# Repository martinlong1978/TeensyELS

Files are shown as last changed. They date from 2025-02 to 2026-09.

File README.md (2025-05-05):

# Teensy Electronic leadscrew
This is an implementation of an electronic leadscrew using a Teensy microcrontroller.

# Architecture
We use [https://platformio.org/](platformio) as the infrastructure to build this project.

# Installation
You will currently need to setup platformio to build this, it can also handle installation to your teensy as well.
NOTE: you will have to modify some of the configuration to get this set up for your particular lathe, instructions coming soon.

# Testing
We aim to have the business logic of this testable locally without having to program any hardware or run tests on hardware (for the most part)
To test you just need to run the `pio test --environment native` command to run what tests we have written

## Debugging
To test this application, you will be limited to setting breakpoints on unit tests only as the Teensy series of boards do not support hardware debuggers directly.

The "blessed" way to debug is to:
- Use vscode
- Set your environment to "native" (this is the default)
- Ensure that 'gdb' is installed
- Set your breakpoints in your code to test
    - note: if you want to debug a single test, set the test name in `test_debug` in platformio.ini
- go to the debug panel in vscode and run the "PIO debug" target
- ???
- Profit!

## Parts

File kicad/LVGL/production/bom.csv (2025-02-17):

Designator | Footprint | Quantity | Value | LCSC Part #
_4, _3, _2, |  | 4
E1 | Sparkfun | 1 | ~
J1 | RJ45_RCH_RC01937 | 1 | RJ45_Shielded
J2 | JST_XH_B4B-XH-A_1x04_P2.50mm_Vertical | 1 | Conn_01x04_Pin
J3 | PinHeader_1x04_P2.54mm_Vertical | 1 | Conn_01x04_Pin
J4 | TerminalBlock_CUI_TB007-508-02_1x02_P5.08mm_Horizontal | 1 | Screw_Terminal_01x02
MCU1 | TTGO-T-Display | 1 | TTGO-T-Display
Q1, Q2, Q3, Q4, Q5, Q6, Q7, Q8 | SOT-23 | 8 | BSS138
R1, R11, R12, R18, R2, R3, R4, R5, R6, R7, R8 | 0805 | 11 | 10K
R10, R9 | 0805 | 2 | 330R
R13, R14 | 0805 | 2 | 0K
R15, R16, R17 | 0805 | 3 | 1K
SW1, SW10, SW2, SW3, SW4, SW5, SW6, SW7, SW8, SW9 | SW_TH_Tactile_Omron_B3F-10xx | 10 | SW_Omron_B3FS
U1 | Teensy41 | 1 | Teensy4.1

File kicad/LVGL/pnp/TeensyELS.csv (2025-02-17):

Id | Designator | Footprint | Quantity | Designation | Supplier and ref
1 | Q3,Q8,Q7,Q2,Q5,Q1,Q4,Q6 | SOT-23 | 8 | BSS138
2 | R18,R4,R11,R12,R7,R1,R6,R3,R15,R17,R16,R5,R2,R8 | R_0805_2012Metric | 14 | 10K
3 | MCU1 | TTGO-T-Display | 1 | TTGO-T-Display
4 | ,,, |  | 4
5 | J2 | JST_XH_B4B-XH-A_1x04_P2.50mm_Vertical | 1 | Conn_01x04_Pin
6 | J4 | TerminalBlock_CUI_TB007-508-02_1x02_P5.08mm_Horizontal | 1 | Screw_Terminal_01x02
7 | U1 | Teensy41 | 1 | Teensy4.1
8 | SW8,SW6,SW1,SW3,SW4,SW2,SW7,SW5,SW9,SW10 | SW_TH_Tactile_Omron_B3F-10xx | 10 | SW_Omron_B3FS
9 | R14,R13 | R_0805_2012Metric | 2 | 0K
10 | R9,R10 | R_0805_2012Metric | 2 | 330R
11 | J1 | RJ45_RCH_RC01937 | 1 | RJ45_Shielded
12 | J3 | PinHeader_1x04_P2.54mm_Vertical | 1 | Conn_01x04_Pin
13 | E1 | Sparkfun | 1 | ~

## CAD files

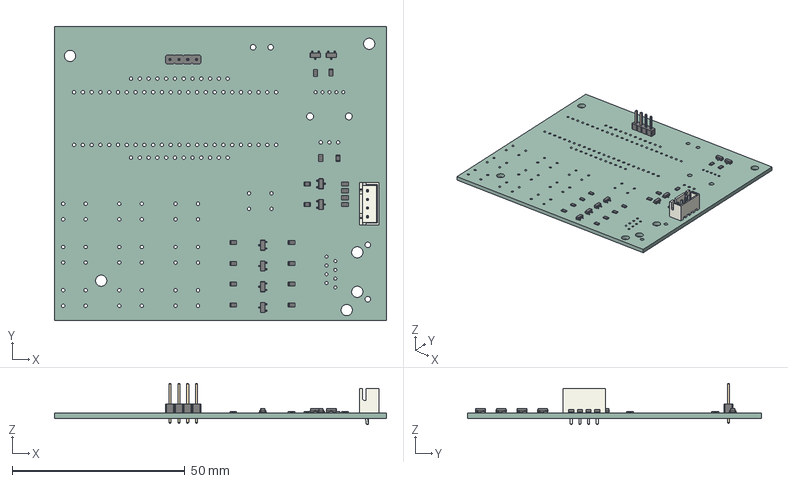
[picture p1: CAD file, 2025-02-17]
kicad/LVGL/TeensyELS.step
96.0 x 85.0 x 11.9 mm
SOT_23 x 8
R_0805_2012Metric x 18
JST_B4B_XH_A
PinHeader_1x04_P254mm_Vertical
TeensyELS_PCB

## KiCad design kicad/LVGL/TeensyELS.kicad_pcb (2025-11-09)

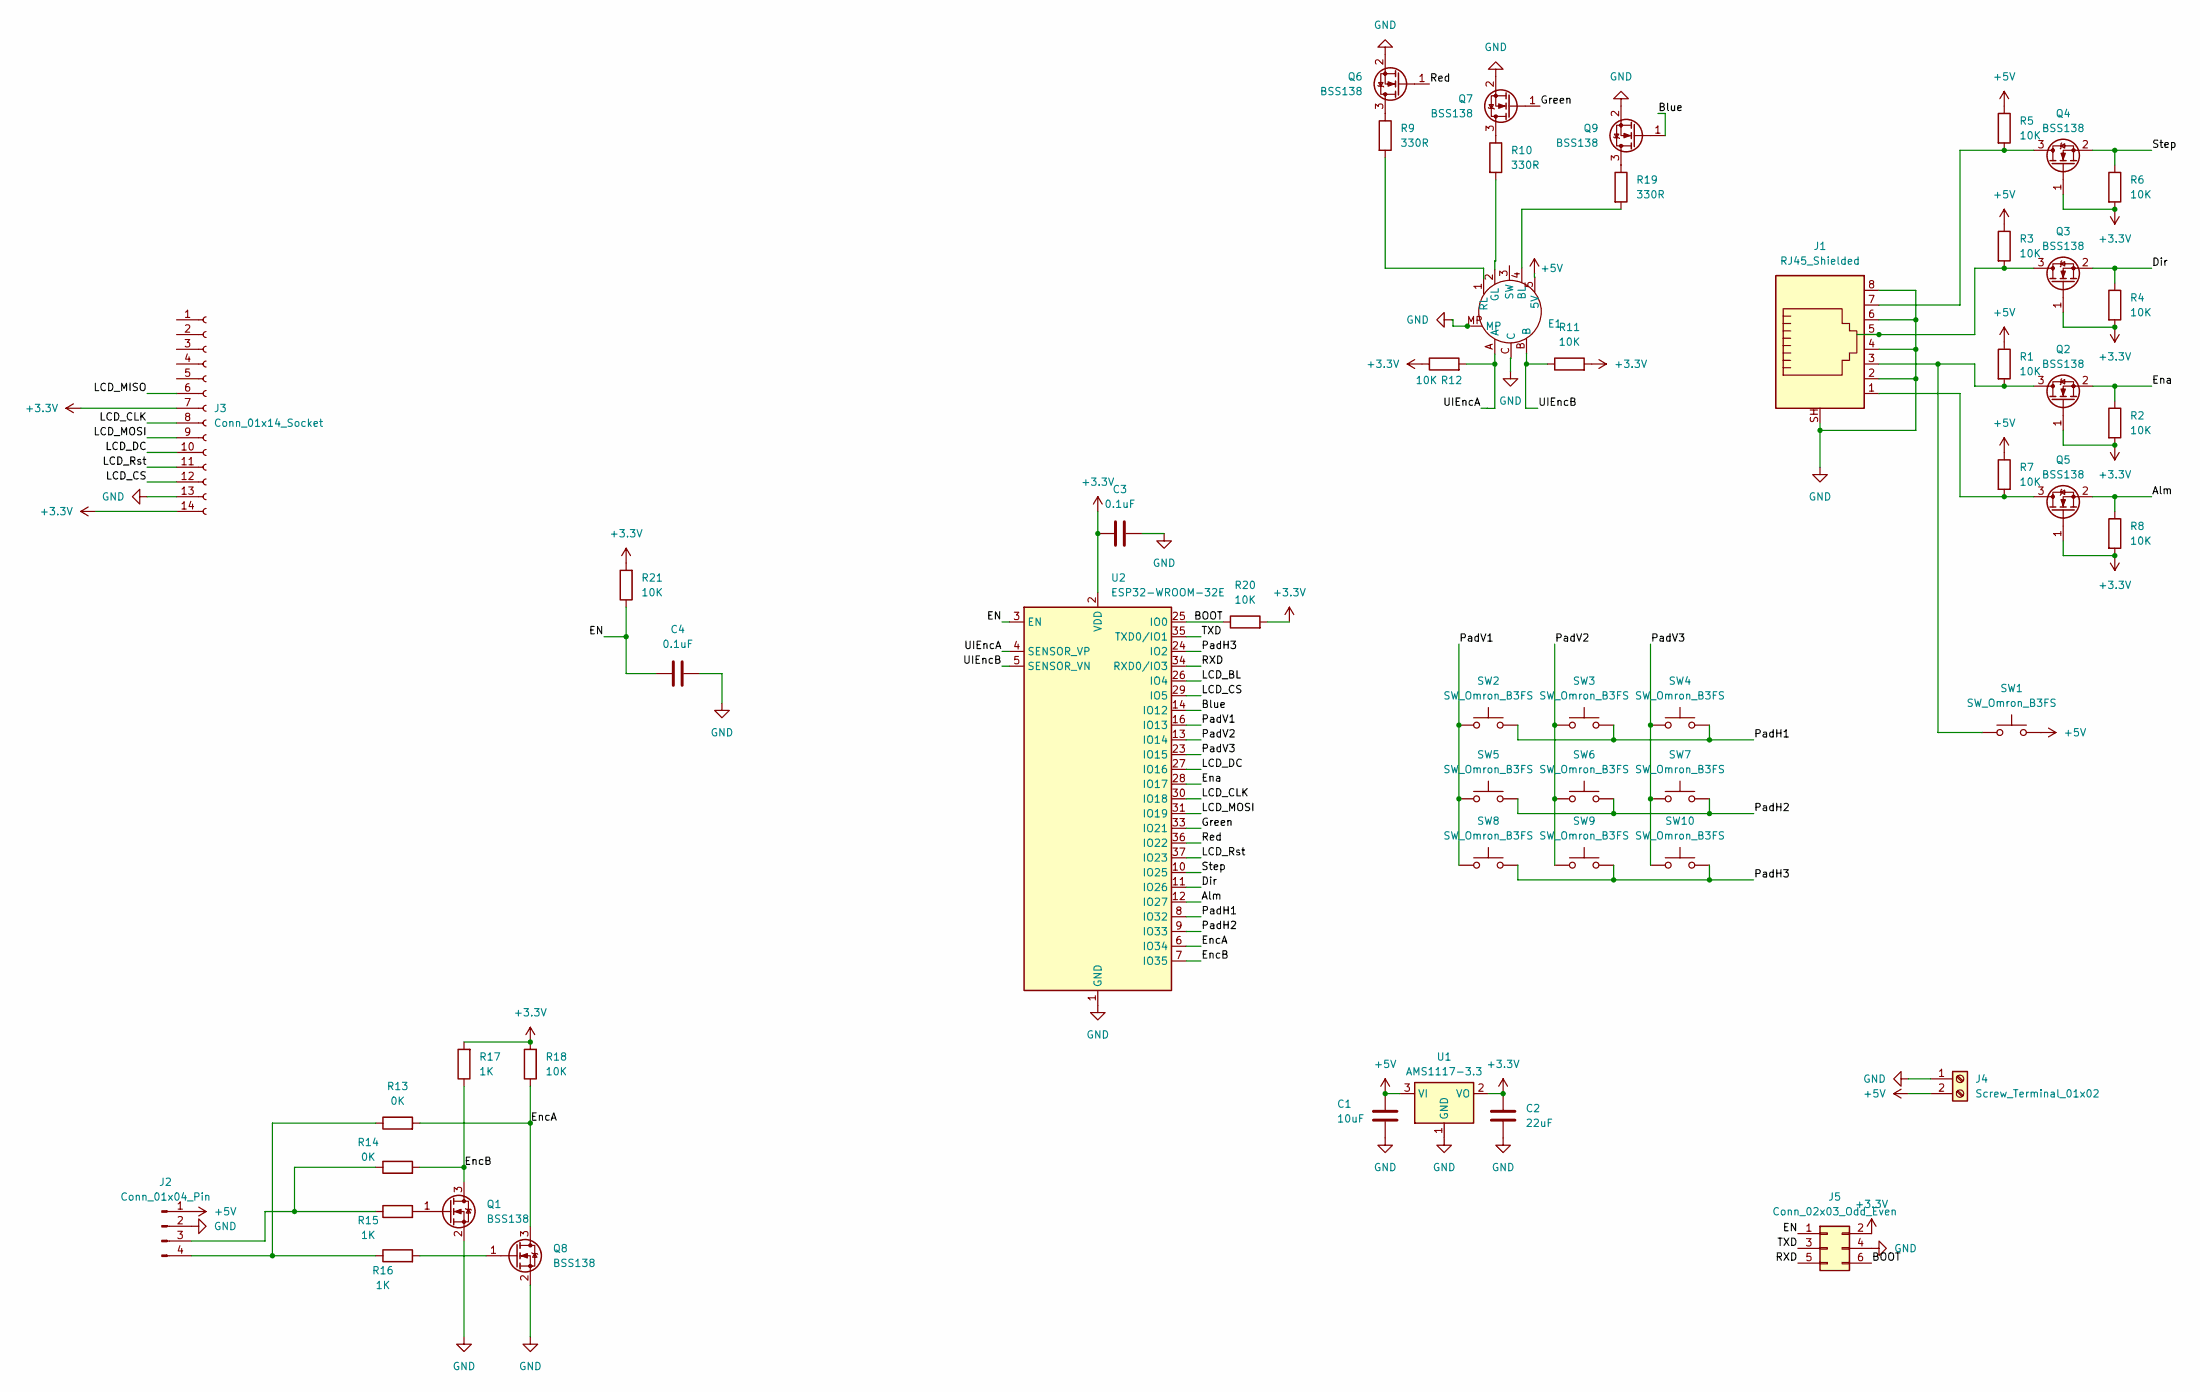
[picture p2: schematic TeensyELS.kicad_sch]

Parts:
C1: 10uF; C_0805_2012Metric
C2: 22uF; C_0805_2012Metric
C3, C4: 0.1uF; C_0805_2012Metric
E1: Sparkfun
J1: RJ45_Shielded; RJ45_RCH_RC01937
J2: Conn_01x04_Pin; JST_XH_B4B-XH-A_1x04_P2.50mm_Vertical
J3: Conn_01x14_Socket; PinHeader_1x14_P2.54mm_Vertical
J4: Screw_Terminal_01x02; TerminalBlock_CUI_TB007-508-02_1x02_P5.08mm_Horizontal
J5: Conn_02x03_Odd_Even; PinHeader_2x03_P1.27mm_Vertical_SMD
Q1, Q2, Q3, Q4, Q5, Q6, Q7, Q8, Q9: BSS138; SOT-23
R1, R2, R3, R4, R5, R6, R7, R8, R11, R12, R18, R20, R21: 10K; R_0805_2012Metric
R9, R10, R19: 330R; R_0805_2012Metric
R13, R14: 0K; R_0805_2012Metric
R15, R16, R17: 1K; R_0805_2012Metric
SW1, SW2, SW3, SW4, SW5, SW6, SW7, SW8, SW9, SW10: SW_Omron_B3FS; SW_TH_Tactile_Omron_B3F-10xx
U1: AMS1117-3.3; SOT-223-3_TabPin2
U2: ESP32-WROOM-32E; ESP32-WROOM-32D

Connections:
+3.3V: C2.2, C3.1, J3.7, J3.14, J5.2, Q2.1 (G), Q3.1 (G), Q4.1 (G), Q5.1 (G), R2.2, R4.2, R6.2, R8.2, R11.2, R12.1, R17.2, R18.2, R20.2, R21.2, U1.2 (VO), U2.2 (VDD)
+5V: C1.2, E1.5 (5V), J2.1, J4.2, R1.1, R3.1, R5.1, R7.1, SW1.2, U1.3 (VI)
/Alm: Q5.2 (S), R8.1, U2.12 (IO27)
/BOOT: J5.6, R20.1, U2.25 (IO0)
/Blue: Q9.1 (G), U2.14 (IO12)
/Dir: Q3.2 (S), R4.1, U2.11 (IO26)
/EN: C4.1, J5.1, R21.1, U2.3 (EN)
/Ena: Q2.2 (S), R2.1, U2.28 (IO17)
/EncA: Q8.3 (D), R13.2, R18.1, U2.6 (IO34)
/EncB: Q1.3 (D), R14.2, R17.1, U2.7 (IO35)
/Green: Q7.1 (G), U2.33 (IO21)
/LCD_BL: U2.26 (IO4)
/LCD_CLK: J3.8, U2.30 (IO18)
/LCD_CS: J3.12, U2.29 (IO5)
/LCD_DC: J3.10, U2.27 (IO16)
/LCD_MISO: J3.6
/LCD_MOSI: J3.9, U2.31 (IO19)
/LCD_Rst: J3.11, U2.37 (IO23)
/PadH1: SW2.2, SW3.2, SW4.2, U2.8 (IO32)
/PadH2: SW5.2, SW6.2, SW7.2, U2.9 (IO33)
/PadH3: SW8.2, SW9.2, SW10.2, U2.24 (IO2)
/PadV1: SW2.1, SW5.1, SW8.1, U2.16 (IO13)
/PadV2: SW3.1, SW6.1, SW9.1, U2.13 (IO14)
/PadV3: SW4.1, SW7.1, SW10.1, U2.23 (IO15)
/RXD: J5.5, U2.34 (RXD0/IO3)
/Red: Q6.1 (G), U2.36 (IO22)
/Step: Q4.2 (S), R6.1, U2.10 (IO25)
/TXD: J5.3, U2.35 (TXD0/IO1)
/UIEncA: E1.A, R12.2, U2.4 (SENSOR_VP)
/UIEncB: E1.B, R11.1, U2.5 (SENSOR_VN)
GND: C1.1, C2.1, C3.2, C4.2, E1.C, E1.MP, J1.2, J1.4, J1.6, J1.8, J1.SH, J2.2, J3.13, J4.1, J5.4, Q1.2 (S), Q6.2 (S), Q7.2 (S), Q8.2 (S), Q9.2 (S), U1.1 (GND), U2.1 (GND), U2.15 (GND), U2.38 (GND), U2.39 (GND)
unnamed: E1.4 (BL), R19.2
unnamed: E1.2 (GL), R10.2
unnamed: E1.1 (RL), R9.2
unnamed: J2.3, R14.1, R15.1
unnamed: J2.4, R13.1, R16.1
unnamed: Q1.1 (G), R15.2
unnamed: J1.3, Q2.3 (D), R1.2, SW1.1
unnamed: J1.5, Q3.3 (D), R3.2
unnamed: J1.7, Q4.3 (D), R5.2
unnamed: J1.1, Q5.3 (D), R7.2
unnamed: Q6.3 (D), R9.1
unnamed: Q7.3 (D), R10.1
unnamed: Q8.1 (G), R16.2
unnamed: Q9.3 (D), R19.1

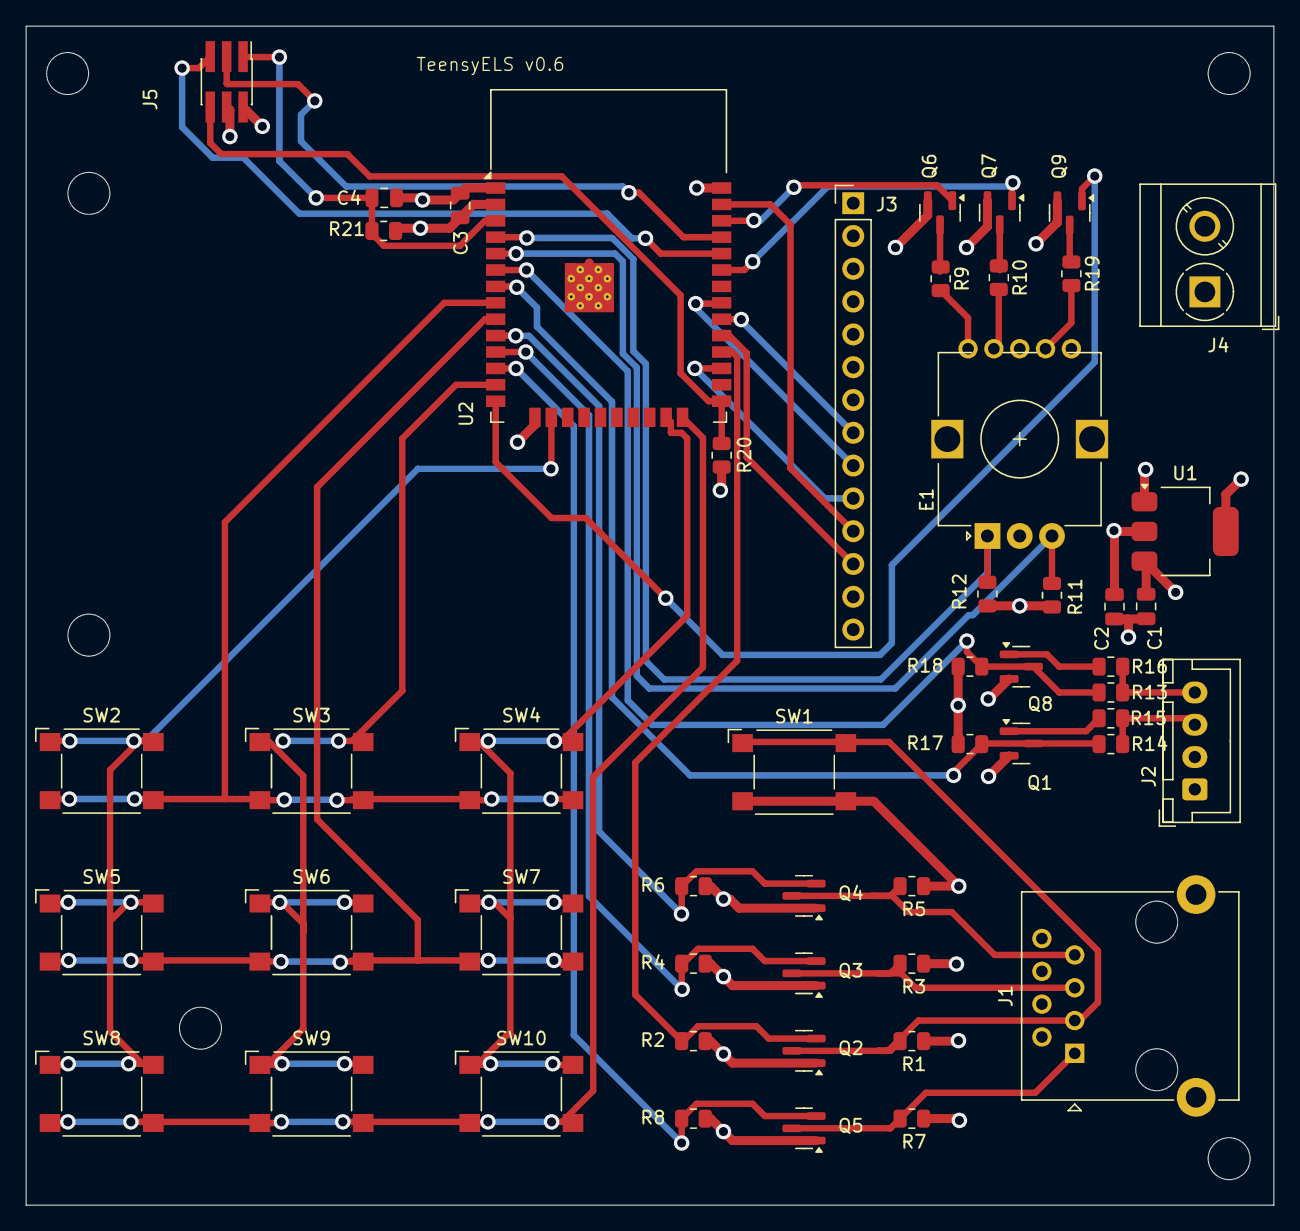
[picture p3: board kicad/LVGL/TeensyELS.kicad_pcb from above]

Board: 4 copper layers, 96.6 x 91.3 mm, 52 parts (0 on the bottom side), 43 nets.

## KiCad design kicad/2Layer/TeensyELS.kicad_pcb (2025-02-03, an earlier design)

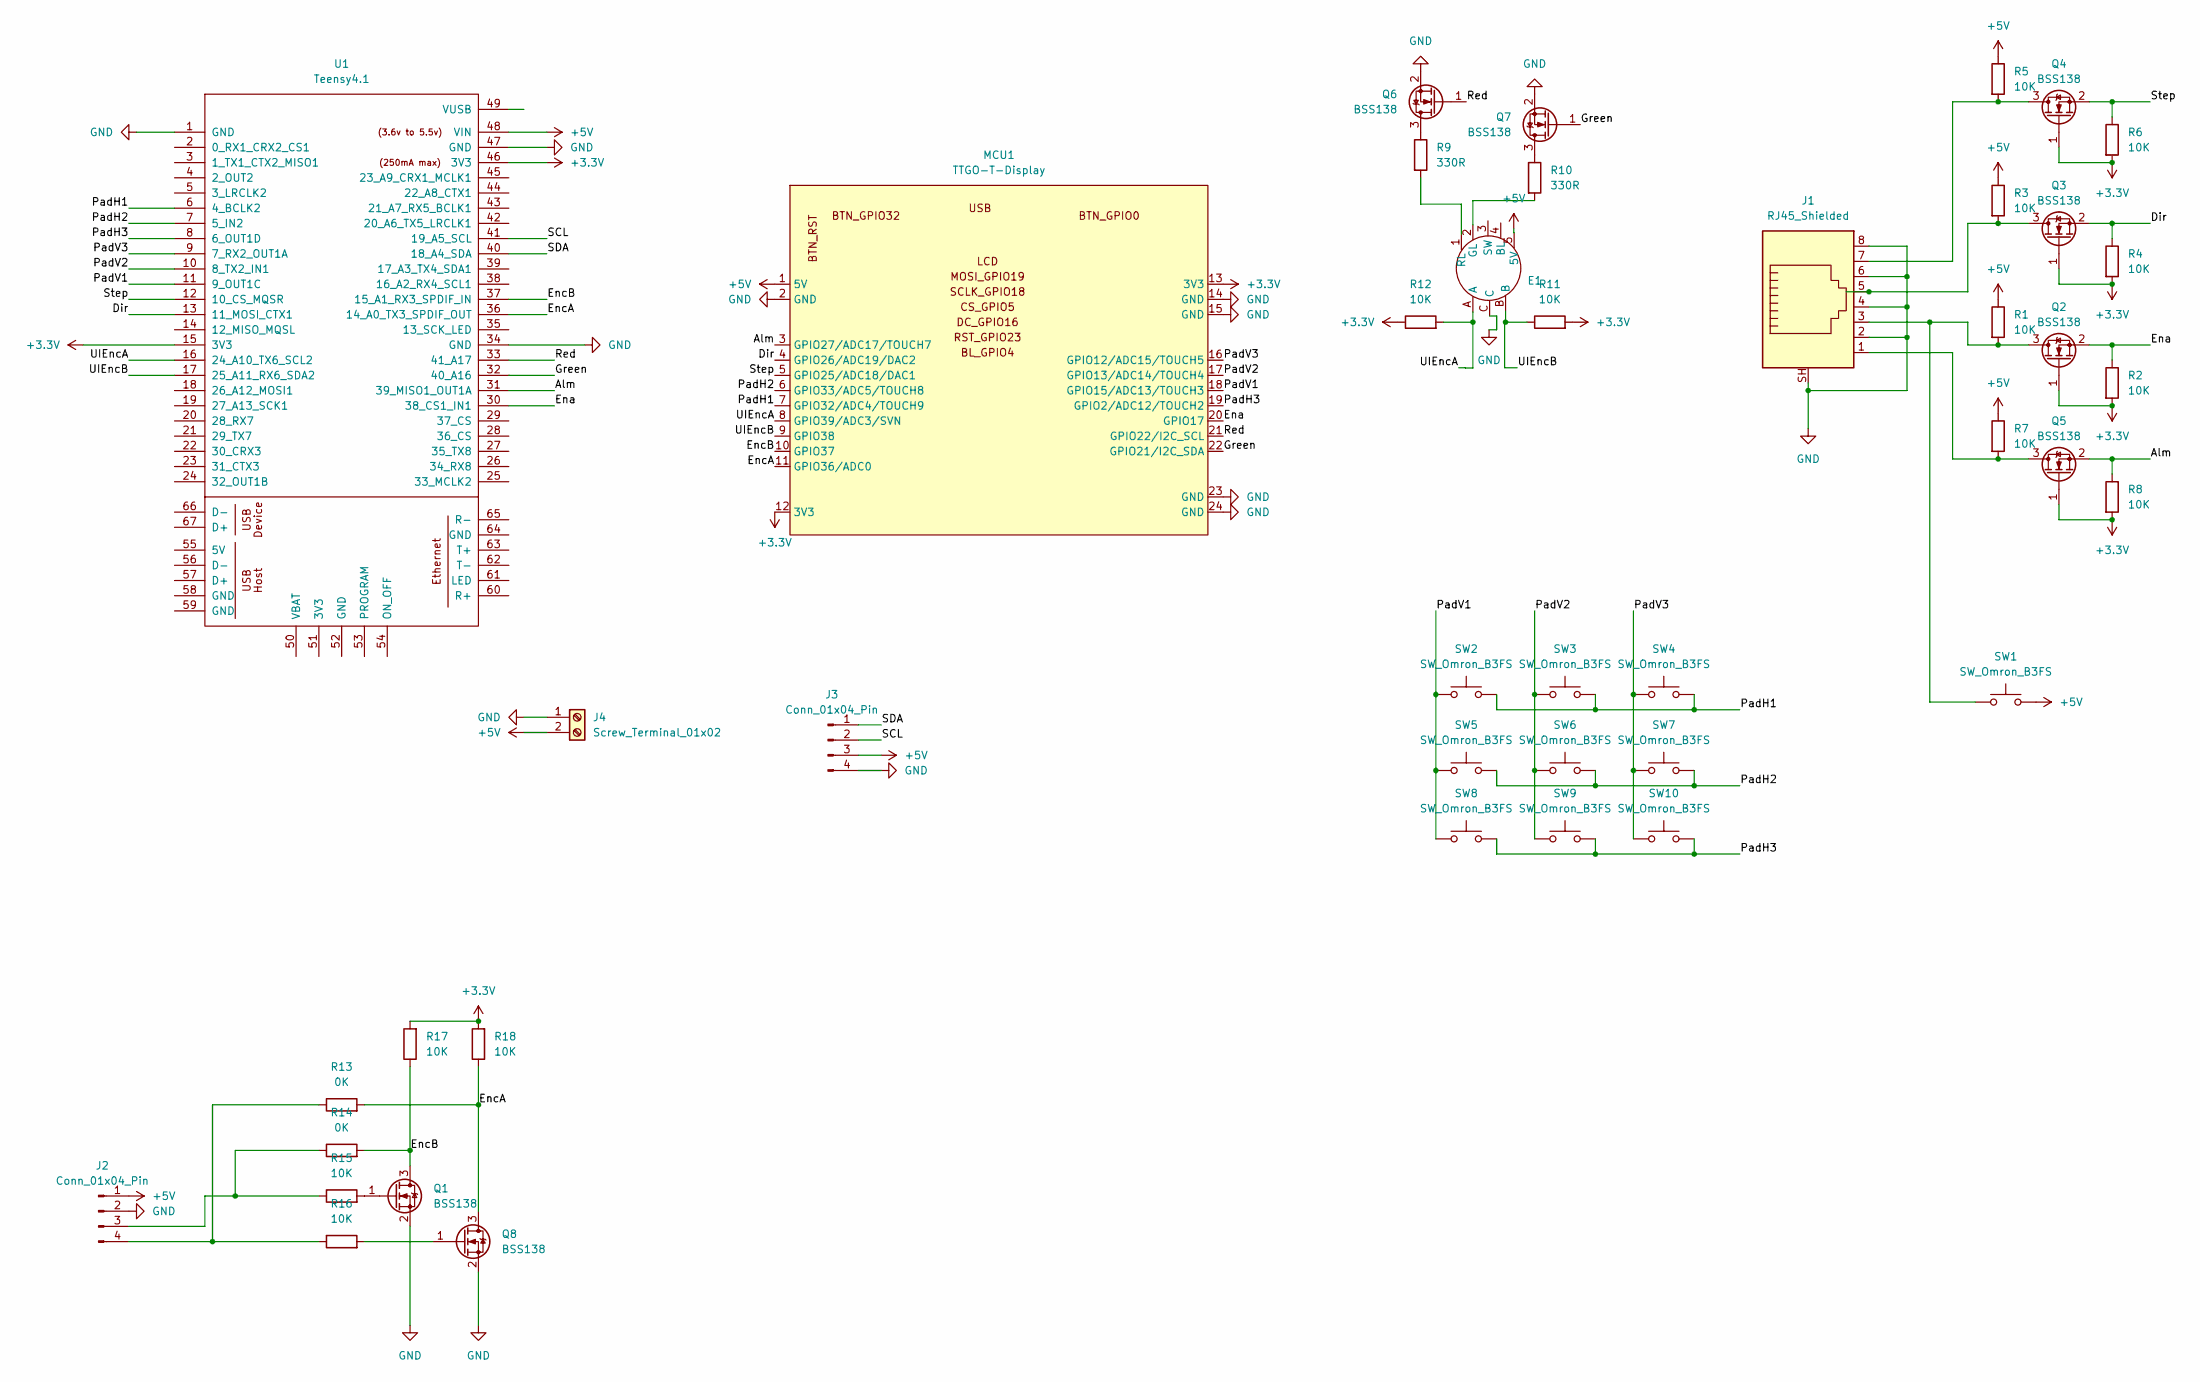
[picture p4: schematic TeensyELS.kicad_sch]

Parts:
E1: Sparkfun
J1: RJ45_Shielded; RJ45_RCH_RC01937
J2: Conn_01x04_Pin; JST_XH_B4B-XH-A_1x04_P2.50mm_Vertical
J3: Conn_01x04_Pin; PinHeader_1x04_P2.54mm_Vertical
J4: Screw_Terminal_01x02; TerminalBlock_CUI_TB007-508-02_1x02_P5.08mm_Horizontal
MCU1: TTGO-T-Display
Q1, Q2, Q3, Q4, Q5, Q6, Q7, Q8: BSS138; SOT-23
R1, R2, R3, R4, R5, R6, R7, R8, R11, R12, R15, R16, R17, R18: 10K; R_0805_2012Metric
R9, R10: 330R; R_0805_2012Metric
R13, R14: 0K; R_0805_2012Metric
SW1, SW2, SW3, SW4, SW5, SW6, SW7, SW8, SW9, SW10: SW_Omron_B3FS; SW_TH_Tactile_Omron_B3F-10xx
U1: Teensy4.1; Teensy41

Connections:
+3.3V: MCU1.12 (3V3), MCU1.13 (3V3), Q2.1 (G), Q3.1 (G), Q4.1 (G), Q5.1 (G), R2.2, R4.2, R6.2, R8.2, R11.2, R12.1, R17.2, R18.2, U1.15 (3V3), U1.46 (3V3)
+5V: E1.5 (5V), J2.1, J3.3, J4.2, MCU1.1 (5V), R1.1, R3.1, R5.1, R7.1, SW1.2, U1.48 (VIN)
/Alm: MCU1.3 (GPIO27/ADC17/TOUCH7), Q5.2 (S), R8.1, U1.31 (39_MISO1_OUT1A)
/Dir: MCU1.4 (GPIO26/ADC19/DAC2), Q3.2 (S), R4.1, U1.13 (11_MOSI_CTX1)
/Ena: MCU1.20 (GPIO17), Q2.2 (S), R2.1, U1.30 (38_CS1_IN1)
/EncA: MCU1.11 (GPIO36/ADC0), Q8.3 (D), R13.2, R18.1, U1.36 (14_A0_TX3_SPDIF_OUT)
/EncB: MCU1.10 (GPIO37), Q1.3 (D), R14.2, R17.1, U1.37 (15_A1_RX3_SPDIF_IN)
/Green: MCU1.22 (GPIO21/I2C_SDA), Q7.1 (G), U1.32 (40_A16)
/PadH1: MCU1.7 (GPIO32/ADC4/TOUCH9), SW2.2, SW3.2, SW4.2, U1.6 (4_BCLK2)
/PadH2: MCU1.6 (GPIO33/ADC5/TOUCH8), SW5.2, SW6.2, SW7.2, U1.7 (5_IN2)
/PadH3: MCU1.19 (GPIO2/ADC12/TOUCH2), SW8.2, SW9.2, SW10.2, U1.8 (6_OUT1D)
/PadV1: MCU1.18 (GPIO15/ADC13/TOUCH3), SW2.1, SW5.1, SW8.1, U1.11 (9_OUT1C)
/PadV2: MCU1.17 (GPIO13/ADC14/TOUCH4), SW3.1, SW6.1, SW9.1, U1.10 (8_TX2_IN1)
/PadV3: MCU1.16 (GPIO12/ADC15/TOUCH5), SW4.1, SW7.1, SW10.1, U1.9 (7_RX2_OUT1A)
/Red: MCU1.21 (GPIO22/I2C_SCL), Q6.1 (G), U1.33 (41_A17)
/SCL: J3.2, U1.41 (19_A5_SCL)
/SDA: J3.1, U1.40 (18_A4_SDA)
/Step: MCU1.5 (GPIO25/ADC18/DAC1), Q4.2 (S), R6.1, U1.12 (10_CS_MQSR)
/UIEncA: E1.A, MCU1.8 (GPIO39/ADC3/SVN), R12.2, U1.16 (24_A10_TX6_SCL2)
/UIEncB: E1.B, MCU1.9 (GPIO38), R11.1, U1.17 (25_A11_RX6_SDA2)
GND: E1.C, J1.2, J1.4, J1.6, J1.8, J1.SH, J2.2, J3.4, J4.1, MCU1.2 (GND), MCU1.14 (GND), MCU1.15 (GND), MCU1.23 (GND), MCU1.24 (GND), Q1.2 (S), Q6.2 (S), Q7.2 (S), Q8.2 (S), U1.1 (GND), U1.34 (GND), U1.47 (GND)
unnamed: E1.2 (GL), R10.2
unnamed: E1.1 (RL), R9.2
unnamed: J2.3, R14.1, R15.1
unnamed: J2.4, R13.1, R16.1
unnamed: Q1.1 (G), R15.2
unnamed: J1.3, Q2.3 (D), R1.2, SW1.1
unnamed: J1.5, Q3.3 (D), R3.2
unnamed: J1.7, Q4.3 (D), R5.2
unnamed: J1.1, Q5.3 (D), R7.2
unnamed: Q6.3 (D), R9.1
unnamed: Q7.3 (D), R10.1
unnamed: Q8.1 (G), R16.2

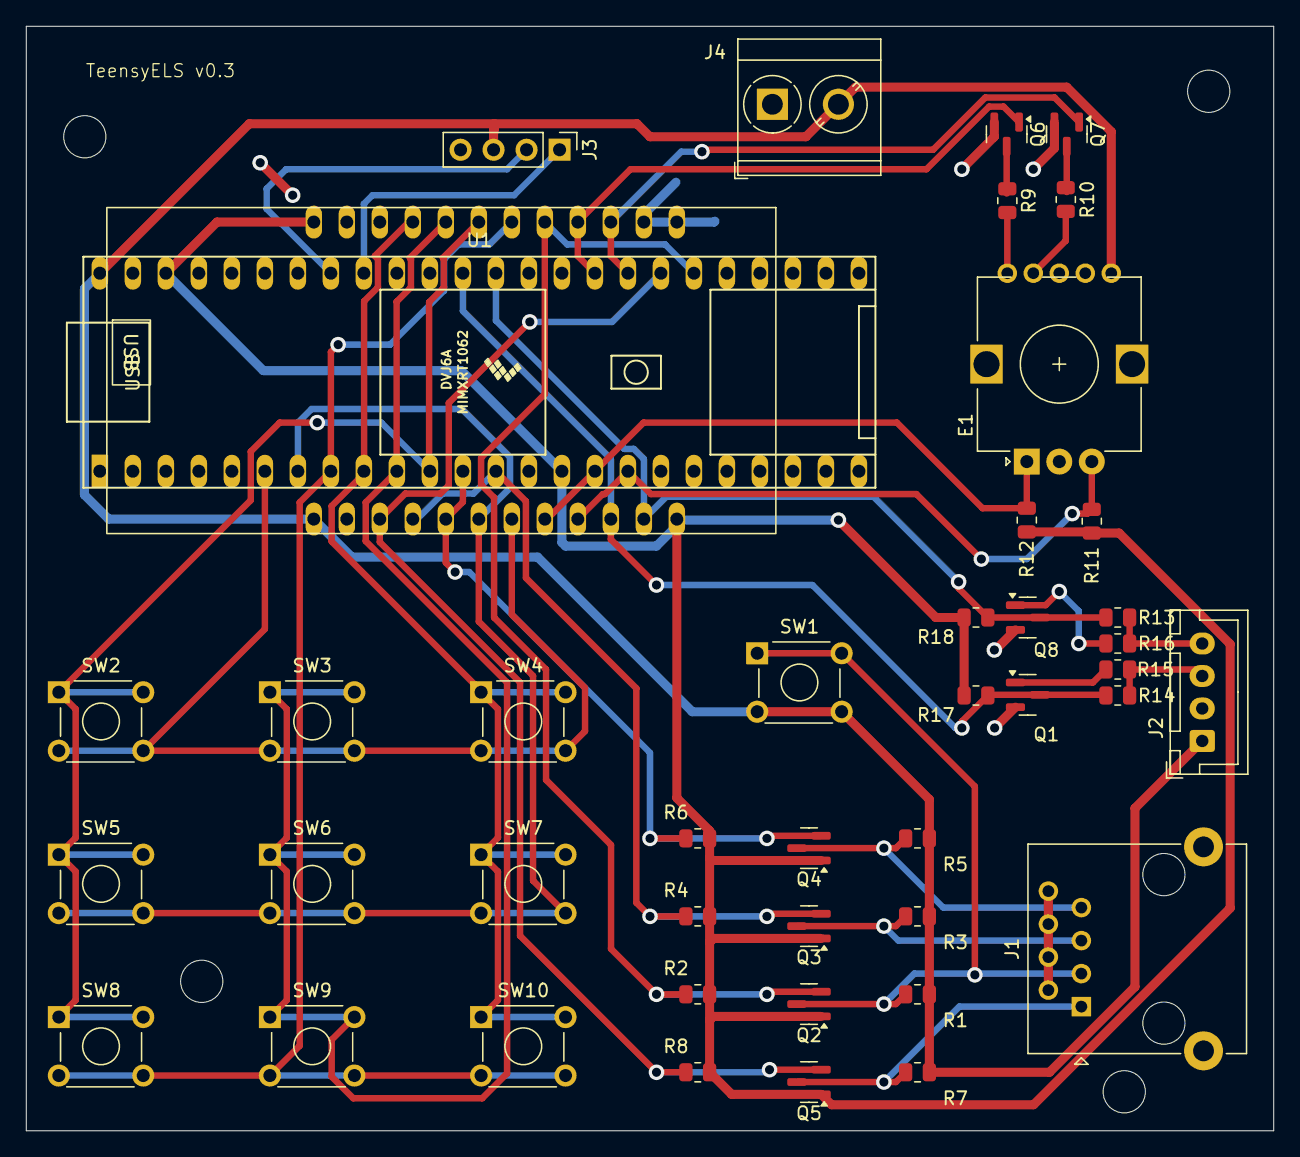
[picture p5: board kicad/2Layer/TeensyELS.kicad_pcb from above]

Board: 2 copper layers, 96.0 x 85.0 mm, 43 parts (0 on the bottom side), 33 nets.

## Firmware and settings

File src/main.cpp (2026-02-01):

// Libraries
#include <Arduino.h>
#include <SPI.h>
//#include <Wire.h>
#include <globalstate.h>
#include <leadscrew.h>
#include <spindle.h>

#include "WebSettings.h"

#include "ESPCommsManager.h"
#include <WiFi.h>

#include "buttonpad.h"
#include "config.h"
#include "display.h"
#include "keyarray.h"

//#define FULLMONITOR
#include <esp_task_wdt.h>
#include <leadscrew_io_esp.h>
#include "latheconfig.h"


Leadscrew* leadscrew;

KeyArray* keyArray;
ButtonPad* keyPad;
Display* display;
Spindle* spindle;

GlobalState* globalState = GlobalState::getInstance();

LeadscrewIOESP leadscrewIOImpl;

ESPCommsManager commsManager;


int64_t lastcycle;
int cyclecount;
int finalcyclecount;
bool configMode = false;


// have to handle the leadscrew updates in a timer callback so we can update the
// screen independently without losing pulses
void timerCallback() {
  if (GlobalState::getInstance()->hasOTA()) {
    commsManager.loop();
  } else {
    spindle->update();
    leadscrew->update();
  }
}


void displayLoop() {
  keyPad->handle();

  display->update();
}

void DisplayTask(void* parameter) {
  // Ensure interrupts are initialised on the right core.  
  keyArray->initPad();
  uint64_t m = 1;
  while (true) {
    displayLoop();
    esp_task_wdt_reset();
    //uint64_t c = micros();
    //uint64_t delay = (100000 - (c - m)) / 1000;
    //if (delay > 0) {
      //vTaskDelay((delay > 100 ? 100 : delay) / portTICK_PERIOD_MS);
    vTaskDelay((100) / portTICK_PERIOD_MS);
    //}
    //m = c + 100000;
  }
}

void SpindleTask(void* parameter) {
  while (true) {
    timerCallback();
    esp_task_wdt_reset();
  }
}

void comms_loop(void* parameters) { commsManager.loop(); }


const char* ssid = "ELS_Wifi";
const char* password = "123456789";

//WiFiServer server;

void runWifiSettings() {
  configMode = true;
  WiFi.mode(WIFI_AP);
  delay(100);
  bool result = WiFi.softAP(ssid, password);
  if (result == true) {
    Serial.println("Access Point Ready");
    Serial.println(WiFi.softAPIP()); // Prints 192.168.4.1
  } else {
    Serial.println("Access Point Failed!");
  }
  IPAddress IP = WiFi.softAPIP();
  Serial.print("AP IP address: ");
  Serial.println(IP);
  //server.begin();
  display->showWifi(ssid, password, IP);
  startWebServer();
}

void setup() {


  Serial.begin(921600);

  pinMode(ELS_PAD_H2, INPUT_PULLDOWN);
  pinMode(ELS_PAD_V2, OUTPUT);
  digitalWrite(ELS_PAD_V2, 1);

  WebSettings* webSettings = getWebSettings();
  LatheConfig* config = getLatheSettings();

  bool checks = (webSettings->check == CHECKVALUE) && (config->check == CHECKVALUE); 

  if (digitalRead(ELS_PAD_H2) == 1 || !checks) {
    display = new Display();
    Serial.println("AP setting mode\n");
    runWifiSettings();
  } else {


    Serial.printf("SSID %s\n", webSettings->ssid);
    Serial.printf("password %s\n", webSettings->password);
    Serial.printf("url %s\n", webSettings->url);


    LatheConfigDerived* derivedConfig = new LatheConfigDerived(config);

    spindle = new Spindle(ELS_SPINDLE_ENCODER_A, ELS_SPINDLE_ENCODER_B, derivedConfig);


    leadscrew = new Leadscrew(derivedConfig, spindle,
      &leadscrewIOImpl,
      derivedConfig->accellerationPulseSec(),
      derivedConfig->leadscrewInitialPulseDelay(),
      derivedConfig->stepperPpr() * derivedConfig->gearboxRatio(),
      derivedConfig->leadscrewPitchMm(), derivedConfig->spindleEncoderPpr());

    keyArray = new KeyArray(leadscrew);
    keyPad = new ButtonPad(spindle, leadscrew, keyArray);
    display = new Display(spindle, leadscrew);



    // config - compile time checks for safety
    CHECK_BOUNDS(DEFAULT_METRIC_THREAD_PITCH_IDX, threadPitchMetric,
      "DEFAULT_METRIC_THREAD_PITCH_IDX out of bounds");
    CHECK_BOUNDS(DEFAULT_METRIC_FEED_PITCH_IDX, feedPitchMetric,
      "DEFAULT_METRIC_FEED_PITCH_IDX out of bounds");
    CHECK_BOUNDS(DEFAULT_IMPERIAL_THREAD_PITCH_IDX, threadPitchImperial,
      "DEFAULT_IMPERIAL_THREAD_PITCH_IDX out of bounds");
    CHECK_BOUNDS(DEFAULT_IMPERIAL_FEED_PITCH_IDX, feedPitchImperial,
      "DEFAULT_IMPERIAL_FEED_PITCH_IDX out of bounds");

    // Pinmodes


#ifdef ELS_USE_RMT
    rmt_obj_t* leadscreRMT = rmtInit(ELS_LEADSCREW_STEP, true, RMT_MEM_64);
    leadscrew->setRMT(leadscreRMT);
    rmtSetTick(leadscreRMT, 2500);
#else
    pinMode(ELS_LEADSCREW_STEP, OUTPUT); // step output pin
#endif

    pinMode(ELS_LEADSCREW_DIR, OUTPUT);  // direction output pin

#ifdef ELS_UI_ENCODER

#ifdef ELS_IND_GREEN
    pinMode(ELS_IND_GREEN, OUTPUT);
    pinMode(ELS_IND_RED, OUTPUT);
    pinMode(ELS_IND_BLUE, OUTPUT);
    digitalWrite(ELS_IND_BLUE, 0);
#endif
#endif

    pinMode(ELS_STEPPER_ENA, OUTPUT);
    digitalWrite(ELS_STEPPER_ENA, 0);

#ifdef ELS_USE_BUTTON_ARRAY
#else
    pinMode(ELS_RATE_INCREASE_BUTTON, INPUT_PULLUP);  // rate Inc
    pinMode(ELS_RATE_DECREASE_BUTTON, INPUT_PULLUP);  // rate Dec
    pinMode(ELS_MODE_CYCLE_BUTTON, INPUT_PULLUP);     // mode cycle
    pinMode(ELS_THREAD_SYNC_BUTTON, INPUT_PULLUP);    // thread sync
    pinMode(ELS_HALF_NUT_BUTTON, INPUT_PULLUP);       // half nut
    pinMode(ELS_ENABLE_BUTTON, INPUT_PULLUP);         // enable toggle
    pinMode(ELS_LOCK_BUTTON, INPUT_PULLUP);           // lock toggle
    pinMode(ELS_JOG_LEFT_BUTTON, INPUT_PULLUP);       // jog left
    pinMode(ELS_JOG_RIGHT_BUTTON, INPUT_PULLUP);      // jog right
#endif

    // Display Initalisation

    display->init();

    leadscrew->setTargetPitchMM(globalState->getCurrentFeedPitch());

    display->update();


    TaskHandle_t spindleTask;
    TaskHandle_t displayTask;
    //TaskHandle_t commsTask;
    xTaskCreatePinnedToCore(SpindleTask, "Spindle", 4096, NULL, 24 | portPRIVILEGE_BIT, &spindleTask, 0);
    xTaskCreatePinnedToCore(DisplayTask, "Display", 8000, NULL, 1, &displayTask, 1);
    //xTaskCreatePinnedToCore(comms_loop, "Comms", 16000, NULL, 10, &commsTask, 1);
    disableLoopWDT();
    esp_task_wdt_delete(xTaskGetHandle("IDLE0"));
    esp_task_wdt_delete(xTaskGetHandle("IDLE1"));
    esp_task_wdt_delete(spindleTask);
    esp_task_wdt_delete(displayTask);
    //esp_task_wdt_delete(commsTask);

    delay(2000);
  }
}

void loop() {
  if (configMode) {
    wifiLoop();
  } else {
    vTaskDelay(1000);
  }
}

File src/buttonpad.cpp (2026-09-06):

#include <config.h>

#ifdef ELS_USE_BUTTON_ARRAY
#include "buttonpad.h"

#include <config.h>
#include <globalstate.h>
// MenuTile (the index -> tile mapping, shared with the carousel that renders
// it) and menuTileBlock() (the availability rule, likewise shared so the
// screen and this file cannot disagree) live in lib/ui/uistate.h, pulled in
// via buttonpad.h. display.h is still needed here for Display itself - the
// Theme and DRO datum tiles call Display::setTheme()/setDroDatum().
#include <display.h>
#include "alarm.h"
#include "WebSettings.h"
#include "setupmode.h"
// commsManager, for UiIntent::AckOta -> ESPCommsManager::acknowledgeOutcome().
#include "ESPCommsManager.h"

// The one Display, built by main.cpp's setup(). Reached by extern rather than
// injected because ButtonPad is constructed FIRST there (Display's constructor
// takes &keyPad->ui()), so there is no ordering in which it could arrive
// through the constructor. Always null-checked: it is null until setup() gets
// to it, and ButtonPad::handle() only ever runs from the DisplayTask, which is
// started long after.
extern Display* display;

// Mk2 button panel glue (docs/ux-redesign.md Sec. 1-6).
//
// The old file dispatched one handler per verb, each gated on a button lock.
// It is now one path: matrix code -> UiKey, ButtonState -> UiKeyEvent, ask
// UiState, execute the single UiIntent it returns.
//
// The event vocabulary comes straight off KeyArray (src/keyarray.cpp:144-170):
//   short press:  Press -> Click -> Release
//   long  press:  Press -> Hold  -> Release   (no Click after a Hold)
// UiState depends on exactly that stream, so events are passed through
// verbatim - never filtered, coalesced or synthesised here.
//
// The lock is gone from this path (docs/ux-redesign.md Sec. 7): HALT is the
// answer to "stop it now", not a mode that prevents keys working. The lock
// state, its enum, and its accessors on GlobalState have since been deleted
// outright now that lib/display no longer reads it either.

ButtonPad::ButtonPad(Spindle* spindle, Leadscrew* leadscrew, KeyArray* pad)
  : m_spindle(spindle),
  m_leadscrew(leadscrew),
  m_pad(pad),
  m_ui() {
  // ButtonPad is heap-allocated (`new ButtonPad` in main.cpp) and the heap is
  // NOT zeroed, so every member is initialised explicitly - see CLAUDE.md
  // ("Constructors must initialise all members"); relying on implicit zeroing
  // has shipped real bugs in this repo. Every member is in the init list above:
  // the three pointers, and m_ui, whose own constructor initialises its fields.
  //
  // There is no settings copy to seed any more. The old constructor rebuilt an
  // entire LatheConfig here from LatheConfigDerived's accessors, because
  // saveLatheSettings() wrote sizeof(LatheConfig) and any field missed by that
  // list would have been written back as a compiled-in default - overwriting
  // the user's commissioned geometry. Geometry is now web-only and carried
  // through flash by saveLathePreferences(), so the copy, the seeding, and the
  // size assert that guarded it are all gone (see buttonpad.h).
}

bool ButtonPad::codeToKey(int code, UiKey& key) {
  switch (code) {
  case ELS_MODE_BUTTON:  key = UiKey::Mode;  return true;
  case ELS_RATE_BUTTON:  key = UiKey::Rate;  return true;
  case ELS_STOPS_BUTTON: key = UiKey::Stops; return true;
  case ELS_LEFT_BUTTON:  key = UiKey::Left;  return true;
  case ELS_OK_BUTTON:    key = UiKey::Ok;    return true;
  case ELS_RIGHT_BUTTON: key = UiKey::Right; return true;
  case ELS_HALT_BUTTON:  key = UiKey::Halt;  return true;
  case ELS_MENU_BUTTON:  key = UiKey::Menu;  return true;
  // ENABLE is now part of the focus model rather than being intercepted ahead
  // of it. It still does exactly what it did - the ToggleEngage arm of
  // applyIntent() is the old enableHandler() body verbatim - but WHETHER it
  // toggles is now UiState's decision (dismiss first, engage second), which is
  // a decision that has to be host-testable.
  case ELS_ENABLE_BUTTON: key = UiKey::Enable; return true;
  default: return false;
  }
}

bool ButtonPad::stateToEvent(int buttonState, UiKeyEvent& ev) {
  switch (buttonState) {
  case BS_PRESSED:  ev = UiKeyEvent::Press;   return true;
  case BS_CLICKED:  ev = UiKeyEvent::Click;   return true;
  case BS_HELD:     ev = UiKeyEvent::Hold;    return true;
  // The 1 s confirm dwell. Only the destructive gestures look at it.
  case BS_LONG_HELD: ev = UiKeyEvent::LongHold; return true;
  case BS_RELEASED: ev = UiKeyEvent::Release; return true;
  // BS_NONE is the empty-queue marker; BS_DOUBLE_CLICKED is declared but never
  // emitted by KeyArray. Neither has a UiKeyEvent, so drop them.
  default: return false;
  }
}

UiContext ButtonPad::buildContext() {
  GlobalState* globalState = GlobalState::getInstance();
  const GlobalMotionMode motionMode = globalState->getMotionMode();

  UiContext ctx;
  ctx.leftStopSet =
    m_leadscrew->getStopPositionState(LeadscrewStopPosition::LEFT) !=
    LeadscrewStopState::UNSET;
  ctx.rightStopSet =
    m_leadscrew->getStopPositionState(LeadscrewStopPosition::RIGHT) !=
    LeadscrewStopState::UNSET;
  // Engaged: the leadscrew is following the spindle.
  ctx.motionEnabled = (motionMode == GlobalMotionMode::MM_ENABLED);
  // Under power at all - engaged feed, powered run to a stop, interactive jog,
  // or decelerating out of any of those.
  ctx.motionActive = (motionMode != GlobalMotionMode::MM_DISABLED &&
    motionMode != GlobalMotionMode::MM_UNSET);
  // Only menuTileBlock() reads this, for the Sync tile. Sampled from the same
  // GlobalState, at the same instant, as the two motion flags - so the block
  // UiState computes and the one activateMenuTile() recomputes below can only
  // disagree if the machine actually changed in between, which is the race that
  // check exists to catch.
  const GlobalFeedMode feedMode = globalState->getFeedMode();
  ctx.threadMode = (feedMode == FM_THREAD || feedMode == FM_THREAD_REVERSE);
  // The stepper alarm. Latched fault OR reset pulse in flight - both inhibit
  // the machine and both keep the modal up, so UiState sees one flag (see
  // UiContext in lib/ui/uistate.h). Sampled from GlobalState like the rest,
  // where the alarm task publishes it; ButtonPad never touches the AlarmMonitor
  // except to ask for a clear.
  ctx.alarm = globalState->alarmActive();
  // The OTA screen. True for the whole of GlobalState::hasOTA()'s span -
  // connecting/checking/downloading/settled, not only a settled failure - see
  // the long comment on UiContext::ota in lib/ui/uistate.h and the UiStateOta
  // block in test/test_uistate/test_uistate.cpp for why. ButtonPad never talks
  // to ESPCommsManager to READ this; GlobalState is the one bus both tasks
  // already use (see the "Cross-task state" note in CLAUDE.md).
  ctx.ota = globalState->hasOTA();
  return ctx;
}
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

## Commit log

2025-01-04 WIP Esp32 support
2025-01-04 Update the encoder stuff for ESP32
2025-01-04 Made main.cpp work with both Teensy and ESP32
2025-01-05 Working buttons
2025-01-05 Fixes to Teensy build after refactor.
    [buttonpad.cpp, keyarray.cpp, main.cpp]
2025-01-07 Tweaks to get stepper and encoder working
2025-01-11 Adding UI Encoder
2025-01-12 Better FreeRTOS thread initialisation
2025-01-12 Better RPM calculation for ESP32
2025-01-12 Teensy build fixes
2025-01-12 Fix memory shortage in display thread
    [main.cpp]
2025-01-12 Fix inverted ratio calculation for leadscrew
2025-01-21 Fix steps/mm calculation to incorporate gearbox ration
    [main.cpp]
2025-01-31 Added basic kicad board design
    [TeensyELS.kicad_pcb, TeensyELS.kicad_sch]
2025-01-31 Fixed missing traces
    [TeensyELS.kicad_pcb]
2025-01-31 Added 4 layer board
    [TeensyELS.kicad_pcb, TeensyELS.kicad_sch]
2025-01-31 Updated board version
    [TeensyELS.kicad_pcb]
2025-02-03 Fix incorrect pin usage
    [TeensyELS.kicad_pcb, TeensyELS.kicad_sch]
2025-02-03 Updated 2 layer designs
    [TeensyELS.kicad_pcb, TeensyELS.kicad_sch]
2025-02-04 Update encoder reference pos, even when keypad is locked
2025-02-17 Updated board design to fix incorrect pin usage
    [TeensyELS.csv, TeensyELS.kicad_pcb, TeensyELS.kicad_sch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]
2025-02-17 Fixed LED function when lock button pressed.
2025-02-17 Create a stabilised tick for the display function.
    [main.cpp]
2025-02-22 Use optimised GPOI writes for ESP32
2025-02-22 Inver screen and buttons
2025-02-23 Added sample secrets.h file
2025-03-09 Rearrange target pitch formula
2025-03-09 Don't stop with 1 rev of endstop. STop at the endstop
2025-03-09 Revert "Don't stop with 1 rev of endstop. STop at the endstop"
    This reverts commit 3a24a99c1fcc9cacbcf515619ef7a2f2ed0bffd7.
2025-03-09 Fix compilation for both platforms
    [buttonpad.cpp, main.cpp]
2025-03-30 Stable and working on Martin's lathe
    [stats-stop.csv, stats.csv]
2025-03-30 Ignore csv files
    [stats-stop.csv, stats.csv]
2025-04-04 Fully syncing now on ESP32
2025-04-04 Separate out ESP/Teensy leadscrew io implementations
2025-04-04 Removed debug prints, and fixed compile for teensy.
    [buttonpad.cpp, main.cpp]
2025-05-05 Add display reset capability
    [buttonpad.cpp, main.cpp]
2025-05-05 Removed button reference comments
2025-05-05 Don't tie display to board config
2025-05-05 Put all UI encoder logic behind #ifdef
2025-05-05 Re-unify spindle.h
2025-05-05 Added secrets-sample.h to .gitignore
2025-05-12 Increase thread memory
2025-05-13 Init interrupts on correct core
    [main.cpp]
2025-10-30 Added test spindle
    Fix member names
    Parameterise spindle test speed
    Display signed RPM
2025-10-30 Working leadscrew optisation
2025-10-30 Fix judder on decelleration
    [buttonpad.cpp]
2025-11-02 Improved button handling stability
    [keyarray.cpp, main.cpp]
2025-11-09 Updated fab files
    [TeensyELS.kicad_pcb, TeensyELS.kicad_sch]
2025-11-10 Tidied up displays, and added partition table.
    [default_8MB.csv, my_4MB.csv]
2025-11-24 Updated kicad files
    [TeensyELS.kicad_sch]
2025-11-24 Updated pins for new board
2025-11-24 Fixed encoder direction.
2026-01-20 Move board config to separate file
2026-01-20 Remove Teensy support
2026-09-06 Wire up hold-OK DRO zero: it never fired ZeroDro
    UiState already emitted ZeroDro on the OK long-hold, but ButtonPad's
    handler was a documented no-op ("owned by the DRO feature set") because
    there was no store for a manual zero. lib/dro already modelled one
    (DroInput.manualZeroSet/manualZeroPulses) but drawTravel() hard-coded it
    false.
    Display now owns the manual-zero datum, seeded false and never touched by
    resetObjectTree() like m_droDatum: setManualZero() stores the carriage's
    current pulse position (never Leadscrew::setCurrentPosition(), which would
    shift both stops), and clearManualZero() is called from
    setDroDatumPreference() on every re-pick of Left/Right - including the
    idempotent sh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
    [buttonpad.cpp]
